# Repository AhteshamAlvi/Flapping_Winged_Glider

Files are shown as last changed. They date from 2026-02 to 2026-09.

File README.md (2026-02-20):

# Flapping Winged Glider (RoboRaptor)

Bio-Inspired Articulated Wing Glider for Wind Characterization and Flapping Flight Research

Ahtesham Alvi · Piyush Sethy · Saiarun Jayanthi <br>
FIRE Bio-Inspired Robotics — University of Maryland: College Park <br>
Advisor: Dr. Lena Johnson

---
## Table of Contents

- [Overview](#overview)
- [Research Goal](#research-goal)
- [Overview](#overview)
- [Final Firmware Version](#final-firmware-version)
- [Prototyping](#prototyping)
- [Mechanical Design](#mechanical-design)
- [Firmware and Control](#firmware-and-control)
- [Wind Sensing and Data Logging](#wind-sensing-and-data-logging)
- [Experimental Results](#experimental-results)
- [Repository Structure](#repository-structure)
- [Hardware Components](#hardware-components)
- [Key Engineering Insights](#key-engineering-insights)
- [Future Work](#future-work)
- [Acknowledgments](#acknowledgments)
- [License](#license)

---
## Overview

This project develops a bio-inspired, tethered flapping wing glider designed to investigate how atmospheric wind conditions interact with articulated wing kinematics in lightweight robotic flight systems. The platform combines a bird-inspired airframe, servo-actuated flapping wings, onboard sensing, and wind telemetry logging to experimentally characterize the behavior of mechanically flapping gliders under real wind conditions.

The system functions as an aeroelastic test platform rather than a powered drone. Instead of continuous propulsion, it leverages aerodynamic lift from wind while actively modulating wing motion through servo actuation. This enables controlled experiments on wind-assisted flight, flapping dynamics, and structural-aerodynamic coupling in lightweight robotic wings.

---

## Research Goal

The objective is to create a tethered gliding robot with articulating wings capable of measuring and characterizing how wind influences flapping and gliding behavior in bio-inspired aerial robots. The platform enables experimental study of atmospheric energy interaction with mechanical flapping systems and supports exploration of passive-active hybrid flight modes.

---

## Overview

This research project consists of four distinct parts (other than the final report):

Mechanical Structure <br>
A lightweight, bird-inspired winged airframe using carbon-fiber spars, flexible membrane wings, and 3D-printed servo mounts and joints designed to withstand cyclic flapping loads.

Actuation and Control <br>
Metal-gear high-torque servos drive articulated wing spars. Arduino-based firmware controls flapping motion, torque behavior, and receiver input for manual or programmed wing actuation.

Sensing and Telemetry <br>
Onboard sensors measure environmental and motion data (temperature, wind vector components, inertial motion). Data is logged via an OpenLog SD module for time-series analysis.

Experimental Validation <br>
Wind-dependent flight trials are recorded via telemetry logs and video to correlate aerodynamic performance with mechanical and control configurations.

---

## Final Firmware Version

The final integrated control firmware for the RoboRaptor platform is:

**CompleteCode_v6.ino**

This version consolidates:

* Servo flapping control
* High-torque actuation logic
* Receiver/remote input handling
* Sensor acquisition
* OpenLog SD telemetry output

Earlier firmware files (ControlCode_v*, PrecisionControl, HighTorqueMotorControl, etc.) represent intermediate development stages and are retained for reference and historical comparison, but **CompleteCode_v6.ino** should be used for deployment and experiments.

---

## Prototyping

Prototype 1 — Sparrow/Falcon Static Wings <br>
Wooden dowel frame with plastic film wings. Failed due to structural fragility and unstable joints.

Prototype 2 — Sparrow/Falcon with Actuation <br>
Introduced servo mounts and actuating spars. Wooden spars fractured under load during flight.

Prototype 3 — Eagle Glider <br>
Transitioned to carbon-fiber spars and improved wing geometry. Achieved stable gliding flight in winds above ~7 mph.

Prototype 4 — Eagle with Articulated Wings <br>
Integrated servo-driven flapping, electronics plate, and improved membrane material. Achieved controlled flapping and directional flight.

---

## Mechanical Design

The mechanical system focuses on load-bearing servo mounts and articulated wing spars capable of sustaining cyclic flapping stresses.

Key design features:

* Carbon-fiber structural spars for stiffness-to-weight efficiency
* Flexible membrane wings for aeroelastic deformation tolerance
* 3D-printed servo mounts optimized for fatigue resistance
* Modular covers and electronics enclosure
* Bird-inspired wing geometries (Sparrow, Falcon, Eagle models)

Multiple mount iterations reflect optimization for torque capacity, vibration damping, and oscillatory load survival.

---

## Firmware and Control

Arduino-based firmware evolved from simple servo tests to integrated flapping control with torque and input handling.

Functional modules include:

* Servo motion and flapping generation
* High-torque actuation control
* Precision timing and motion tuning
* Receiver input decoding
* Remote interface handling
* Sensor data acquisition
* OpenLog SD telemetry output

Later “CompleteCode” versions integrate these subsystems into a unified controller.

---

## Wind Sensing and Data Logging

Wind and motion data are recorded as time-series telemetry during flight tests. Logged values include environmental and inertial measurements sampled at ~30–35 Hz and written to SD via OpenLog.

Example telemetry fields:

* Timestamp
* Temperature
* Wind vector components
* Resultant wind magnitude
* Inertial motion (gyro/accel)

These datasets support analysis of aerodynamic response, flapping behavior, and environmental coupling.

---

## Experimental Results

The articulated Eagle prototype demonstrated:

* Stable tethered gliding in natural wind
*  Servo-driven flapping motion
*  Directional control capability
*  Successful onboard wind data logging

Performance confirmed that carbon-fiber spars and metal-gear servos resolved earlier structural and torque limitations.

---

## Repository Structure

```
Flapping_Winged_Glider/
  CAD/                      CAD and 3D-print files
  Field_testing_files/      Wind logs and videos
  Glider-Code/              Arduino control code
    basecode_files/           Building blocks of code files
  Final_Research_Report/    Report, poster, bibliography
```

---

## Hardware Components

Arduino Nano microcontroller <br>
MG92B metal-gear servo motors <br>
Carbon-fiber wing spars <br>
Flexible membrane wing material <br>
OpenLog SD data logger <br>
Environmental and inertial sensors <br>
3D-printed structural mounts and joints

---

## Key Engineering Insights

Flapping torque requirements exceed plastic servo capability <br>
Cyclic bending fatigue dominates mount design constraints <br>
Wing inertia and structural stiffness directly affect control tuning <br>
Wind magnitude strongly influences flapping stability <br>
Lightweight aeroelastic structures outperform rigid frames

---

## Future Work

Integrated multi-sensor suite (temperature, IMU, altimeter) <br>
Wireless telemetry transmission <br>
Improved membrane wing material (nylon fabric) <br>
Permanent sealed electronics enclosure <br>
Closed-loop wind-adaptive flapping control <br>
Expanded wing geometry optimization

---

## Applications

Atmospheric energy harvesting research <br>
Bio-inspired aerial robotics <br>
Lightweight flapping wing design <br>
Wind-assisted flight systems <br>
Environmental sensing platforms <br>

---

## Acknowledgments

FIRE Bio-Inspired Robotics Program <br>
University of Maryland: College Park <br>
Dr. Lena Johnson

---

## License

Educational and research use.

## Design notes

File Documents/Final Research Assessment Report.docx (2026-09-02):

Ahtesham Alvi, Piyush Sethy, Saiarun Jayanthi

Professor Lena Johnson

FIRE Bio-Inspired Robotics

July 19, 2024

Final Project Report

This project aimed to create a bird-inspired, tethered gliding robot (kite) with articulating flapping wings capable of measuring and characterizing the effects of atmospheric behavior and wind on mechanical flapping and gliding robots. It is primarily made for research purposes to measure wind since it is a kite glider with little practical application.

Our first prototype was a half-wing taped to a table. It was to figure out how to move the wing with a servo, or if it was even possible to do so with a single motor. The second prototype was taking that and splitting it into two distinct wing shapes, as well as stronger metal geared motors. One was model Sparrow, whose wing shape was based on a House Sparrow, and the other was model Falcon, whose wing shape was based on a Peregrine Falcon. The model Sparrow and Falcon both had too brittle spars because they were made of wooden dowels and black plastic film. So then we transitioned to model Eagle for our third prototype, based on a Golden Eagle. This one used carbon fiber rods and the same black plastic film. In the fourth and final prototype, we changed from a black film to a white one because the black film suffered from deformation in the sun. This model used lighter electronics with an Arduino Nano and an accelerometer but the same metal-geared servo motors.

We faced several technical and mechanical problems throughout the project. One primary challenge was the failure of plastic SG92R servos, which couldn’t adequately move the wing spar. We solved this problem by shifting to MG92B servos which had metal gears and a higher torque. We further faced issues with generating lift with prototypes one and two because of brittle wooden dowels, fragile plastic films and a bad wing shape. To solve this, we upgraded to carbon fiber dowels and used flexible garbage bags that allowed it to withstand strong winds. We also changed the wing shape to more closely resemble that of a bird (Eagle). Moreover, as we shifted our focus to programming the sensors to collect environmental data, we faced technical issues with transmitting or recording the data. This was because we lacked hardware and did not have the required SD card reader or transmitter.

In the future, we plan to use a more permanent nylon fabric and sow our electronics into the body. We would like to create a more permanent enclosure so that we can easily repair/modify the electronics, but not add too much weight, all while protecting them from the elements. Additionally, the goal of monitoring wind data flopped in the end. In the future, it would be better to have a more complete sensor system (temperature, gyroscope, accelerometer, and altimeter) that can also write to an easily accessible file, preferably remotely transmitting it to another device. This data could be used to create a more sophisticated control system. Lastly, we would like to iterate on the kite/wing shape itself: we didn’t have enough time or material to prototype lots of different shapes for the kite body.

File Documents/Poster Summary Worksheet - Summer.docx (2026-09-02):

Poster Summary Worksheet

Teams should use this worksheet to organize their research as preparation for creating their final poster presentation. There are no minimum writing requirements for each question but consider that you will take this information and put it in a poster presentation. Judge your responses accordingly.

Project Background

Write about the background research that informed your team’s robot design. Consider your use of the Application, Inspiration, Method (AIM) research method.

Application

Consider how your robot might be used in the field. For example, wildlife monitoring, water cleanup, or archaeology? Talk briefly about how you imagine it might be used.

Our bird-inspired, tethered gliding robot can be used in various practical applications as we take advantage of its ability to glide with the wind. For example, in wildlife monitoring, the robot's quiet, bird-like motion can aid in observing animals while minimizing disturbances. In environmental research, we can embed atmospheric sensors with the robot to measure wind speed, air pressure, humidity, and other properties. The robot's lightweight design and gliding capabilities also make it ideal for continuous atmospheric monitoring and data collection, as it can fly with the wind without external energy input.

Inspiration

Now explore the world of biology and consider what living thing (plant or animal) might inform a robot design that would fit your application. Consider the field application environment and what animals have adapted to it. Also, you can think about natural capabilities in general that might improve the robot design.

Describe what specific traits, forms, functions or behaviors make this a good robot inspiration (For example, can it go deep underwater? Traverse different terrains? Get into small holes?).

Traits across different avian species have inspired our robot design. Our design has large wings and a lightweight design influenced by the biology of dynamic soaring, as birds can detect wind gradients and adjust their flight path for maximum efficiency. By prototyping our robot based on these traits, we utilized these features to fly more efficiently without relying on extended battery usage. Moreover, we also mimicked the adaptive wing features of eagles and hawks to optimize our different flight modes, such as gliding without constantly flapping.

Evaluate the inspiration’s taxonomy. Where does it sit in the taxonomy charts? What specific taxonomic traits are shared across the family or the order that are of use.

The taxonomy of the three birds that inspired our robot design are:

- Hawk → Order: Accipitriformes, Family: Accipitridae
- Sparrow → Order: Passeriformes, Family: Emberizidae
- Eagle → Order: Accipitriformes, Family: Accipitridae
  - We designed our wings to be adaptive so they can flap and glide. Hawks and eagles combine flapping with gliding to optimize energy use during flight. Moreover, eagles have strong, versatile wings that can adjust shape for various flight conditions, so we incorporated them into our design.
- Albatross → Order: Procellariiformes, Family: Diomedeidae
  - Albatrosses have lightweight bodies and large wingspans, which allow them to use wind energy to stay aloft with minimal flapping and thus conserve a lot of energy.

Mechanism

Breakdown the mechanism by which the creature does its thing. Does it crawl, fly, walk, slither? What muscles, body structures, organs or sensors enable this function?

- https://flexbooks.ck12.org/cbook/ck-12-advanced-biology/section/16.32/primary/lesson/bird-structure-and-function-advanced-bio-adv/
- https://www.frontiersin.org/journals/physiology/articles/10.3389/fphys.2020.01038/full

Aside from their well-developed wings, hawks and eagles have numerous structural adaptations that allow them to perform exceptionally well in various conditions. Their skeletons are lightweight yet maintain the strength required to withstand powerful winds. Their bones are fused together in their skeleton, creating rigidity at the joints. This allows them to withstand any stress or concussion generated during maneuvering mid-air. Their keeled sternum provides strong anchorage for powerful flight muscles like the pectoralis major, and together, they can generate the strong wing strokes required for flight. Furthermore, the respiratory system of birds, distinguished by distinct air sacs and parabronchi, helps them to meet the high metabolic demands of flight.

What are the biophysics or physics principles that underly this mechanism? For example, does the animal use Lift to overcome Drag and fly? Does the creature expand and contract with Tension? Does it swim because it is very buoyant?

The robot's design is derived from that of a delta kite. This enables it to catch the wind without relying exclusively on the flapping mechanism to generate lift. Two important considerations are the robotic system's weight and the drag it experiences as it glides. The robot is designed to avoid becoming unbalanced and veering off course.

Project Goal and Design

Describe the goal and design of your robot. Discuss your design process. In other words, how your design was developed? How did you go from original concept design to final idea?

The project aims to create a bird-inspired, tethered gliding robot (kite) with articulating flapping wings capable of measuring and characterizing the effects of atmospheric behavior on mechanical gliding. We followed an iterative design process, continuously improving different parts of the design. At first, we studied several research papers on flapping mechanisms and traits of various bird species to understand the physics of bird flight. Based on the insights we got from research and flying a delta kite, we created basic sketches of different delta kites with rough dimensions for our spars. Moreover, we centered our design choices on two wing shapes to experimentally deduce the most efficient wing shape. While prototyping, we considered several different materials, such as wooden dowels, carbon fibers, and clear and black plastic film. Finally, we created four prototypes and tested them over time. Based on several flight tests, we decided to design our kite with carbon fiber and plastic film.

Briefly consider how the bio mechanisms you found might inform a design? What do you think is the technological analog to the mechanism? Would the design be large or small? Use motors, propellors or wings?

The main biomechanics that informed our design was the flapping mechanism. While birds use their powerful sternum and pectoral muscles to produce powerful wing strokes, we had to iteratively design different methods to replicate this motion. At first, we couldn’t generate the flapping motion in the spar as the SG92R servo was too weak to move the wooden spar. Also, it heated up too quickly. We upgraded to high torque and metal MG92B servos and achieved a consistent flapping mechanism. We were able to move the wing spar for several minutes continuously before the servo heated up.

Current Progress

Describe the current progress your team has made on your robot project.

Describe your concept sketches. How did they help your team create a mind map of the possible ideas? How did your team eventually narrow down the ideas to your final concept? What parameters did you use to “test” the different ideas?

The two initial designs are referred to as Sparrow and Falcon. Sparrow uses a wider wing design with several supporting spars. The bigger surface area was theorized to gather atmospheric wind more efficiently, generating a greater amount of lift.

Falcon uses a curved, sharper wing with no supporting spars. This design was built to emulate the streamlined nature of several avian species with high-speed wing shapes.

While brainstorming sketches, we considered several parameters, including aerodynamic efficiency, structural integrity, and weight. Our initial designs were lightweight, but the joint structures were weak, so they could not support their own weight. We designed and printed connectors to improve the overall integrity of the kite.

Describe the systems of your final idea. What type of systems did your team design? What was the overall shape of the robot? What kind of actuation are you planning? What materials will it be made of? How are you proposing to design the electric circuit? Include pencil sketches and CAD models if you have them.

The final iteration is referred to as Eagle. The weight of the electronics became a concern, so an Arduino Nano with a smaller battery and a smaller breadboard was used. Eagle uses a thinner carbon fiber rod frame for increased flexibility and durability. Additionally, we decided to change the color of the plastic material from black to white because the black material heated too quickly in the sun and deformed during flight.

Describe the preliminary prototypes of your robot. Have you done any testing? What was the outcome? How did it affect the design?

Our preliminary prototypes were made from wooden dowels and plastic film. We carved out two sketches for the wing shape, and based on those, we prototyped and tested both of these designs in the field. Unfortunately, both of these prototypes only took flight for a few seconds. While several variables are crucial for winged robots to take and stay in flight, we deduced that factors like the stiff dowels and fragile bags were the primary reasons behind the failed kite test. Moreover, we considered changing the design of our wings as it was possible that they weren’t catching enough air for lift. After all these design considerations and testing, our final design is made from carbon fibers and stronger plastic film that withstands the constraints of flight.

Team Kite

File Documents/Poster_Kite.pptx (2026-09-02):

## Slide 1

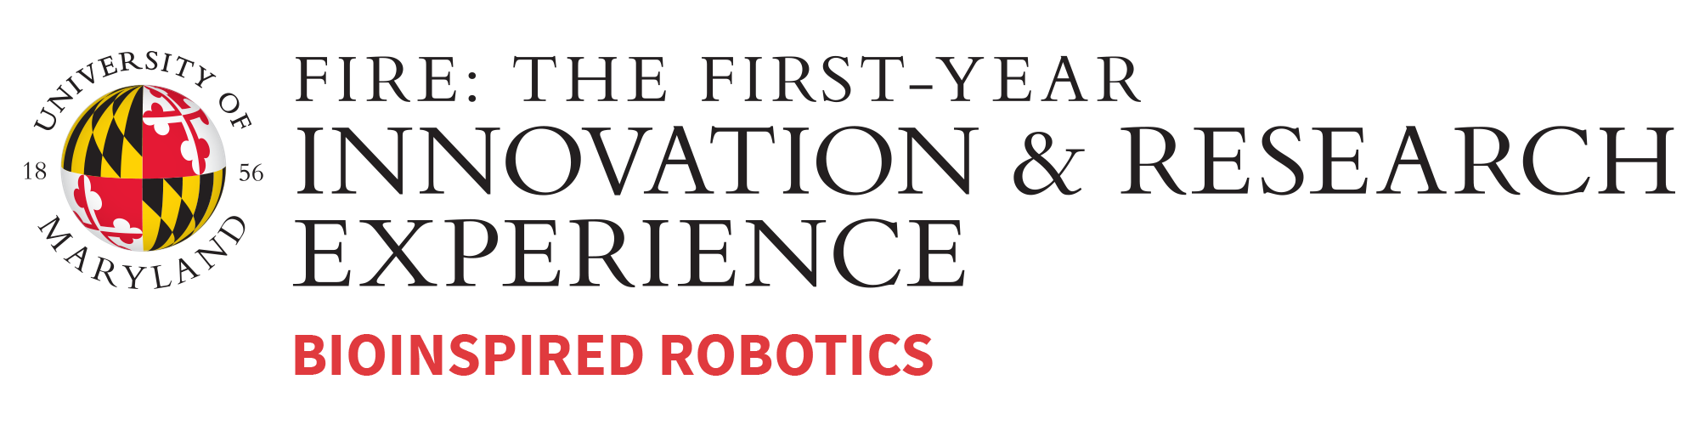
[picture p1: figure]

Goal

This project aims to create a bird-inspired, tethered gliding robot (kite) with articulating flapping wings capable of measuring and characterizing the effects of atmospheric behavior and wind on mechanical flapping and gliding robots.

RoboRaptor: Articulated Wing Glider
Ahtesham Alvi, Piyush Sethy, Saiarun Jayanthi, and Dr. Lena Johnson

Prototype 1: Sparrow & Falcon

- Large wings made with plastic film and a lightweight frame made up of wooden dowels
- Failure: Unable to fly due to unstable joints and fragile plastic body

Prototype 2: Sparrow & Falcon with Actuating Wings

- Improved design with 3D printed servo mounts, end connectors, servo wing spars, and a middle hinge connector
- Used flexible black film, which was more resistant to wind
- Incorporated electronics and servos into the kite
- Failure: Wooden dowels were too stiff and broke during flight test

Prototype 3: Eagle

- Transitioned the frame from wooden dowels to carbon fiber and aluminum
- Adjusted the wing shape based on dimensions of an eagle
- Success: Was able to take flight with winds above 7 mph

Prototype 4: Eagle with Actuating Wings

- Added servos and actuating wings with 3D printed wing arms and mounts
- Used a white film as it is lighter and better suited for hotter climates
- Used a 3D printed plate to incorporate all electronics, including wind sensor
- Success: Was able to fly with the ability to flap and turn

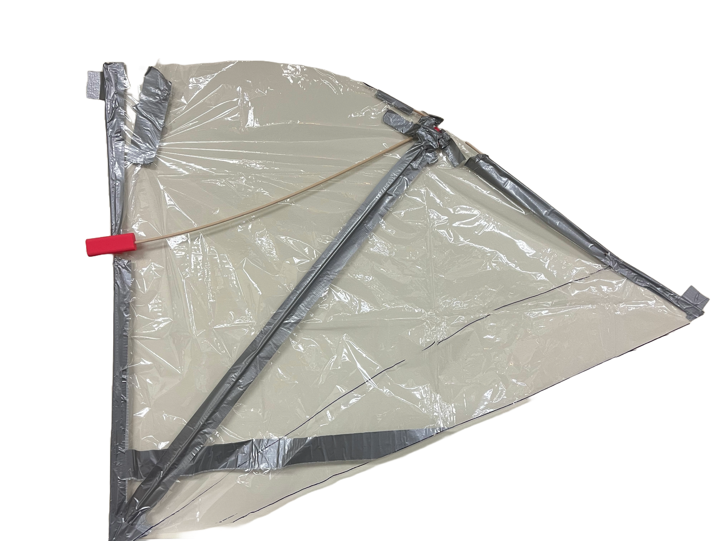
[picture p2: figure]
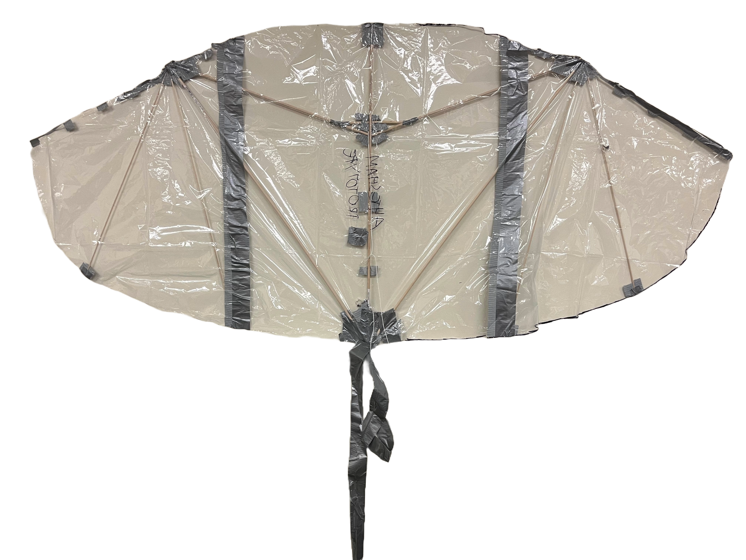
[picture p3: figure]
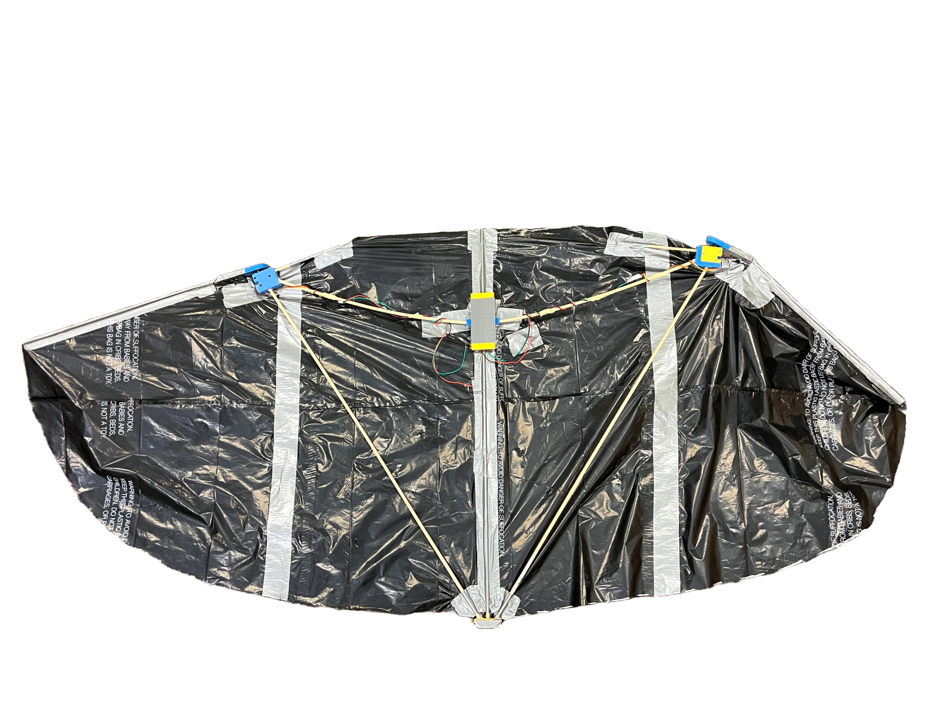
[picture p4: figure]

Background

Unlike traditional drones which require a constant external power source for propulsion, gliding robots leverage aerodynamic efficiency to sustain flight by using the gliding and soaring behavior of birds. [1] This enables them to fly without requiring continuous power input, making them especially valuable for environmental monitoring and data collection. [2]

Governing Principles

Aspect Ratio: The ratio of the length of the wings to their width. It is calculated by dividing the square of the wingspan by the area of the wing. [3] Our kite has a high aspect ratio, which enables it to glide without relying exclusively on flapping
to generate lift.

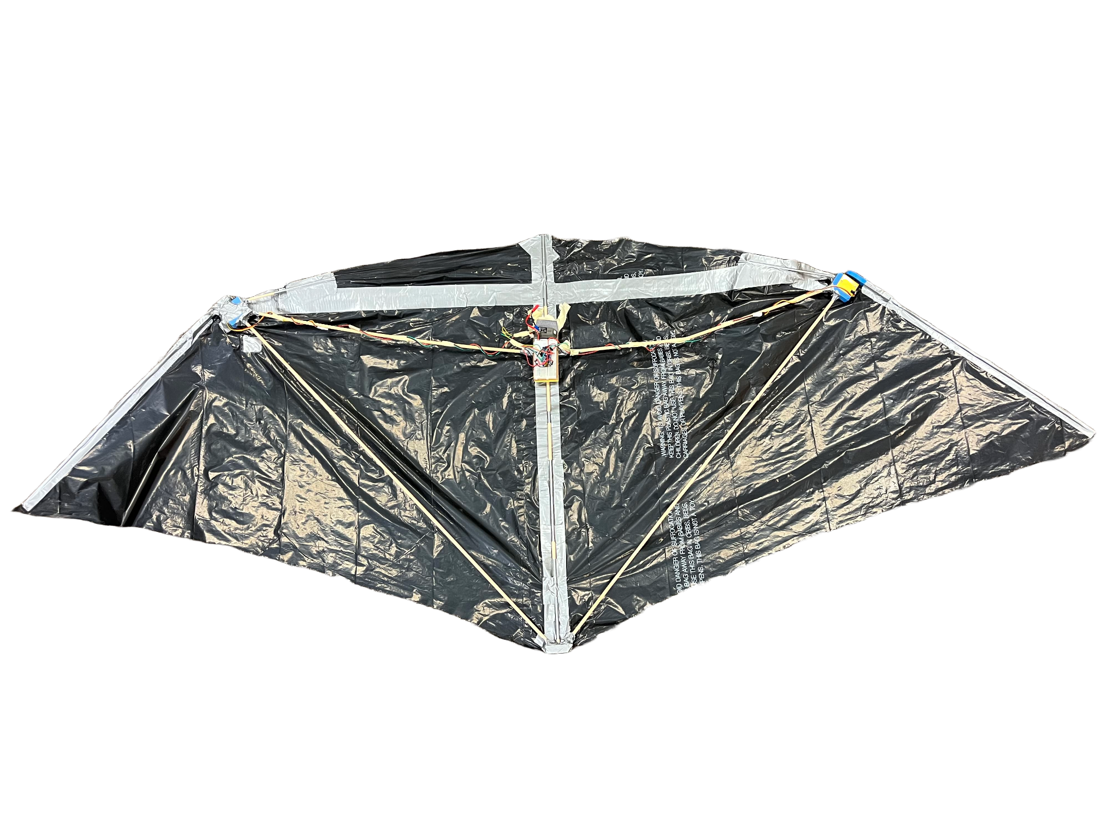
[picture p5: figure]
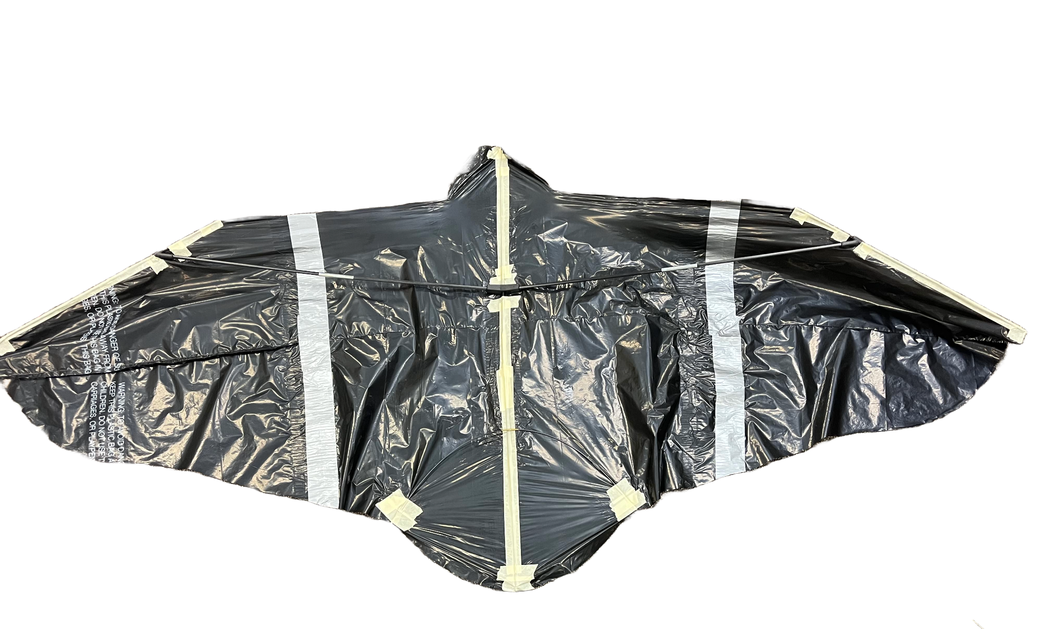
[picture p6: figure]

Wind Data:

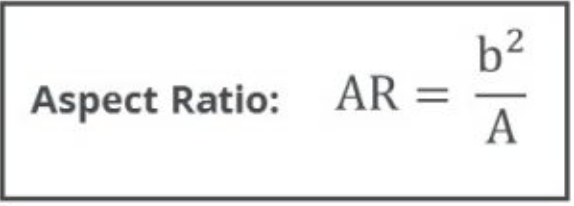
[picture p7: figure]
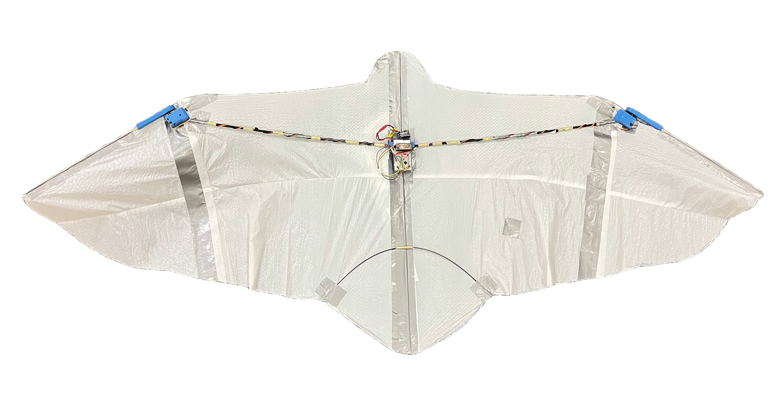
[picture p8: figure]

References
[1] A. Mohamed, G. K. Taylor, S. Watkins, and S. P. Windsor, “Opportunistic soaring by birds suggests new opportunities for atmospheric energy harvesting by Flying Robots,” Journal of The Royal Society Interface, vol. 19, no. 196, Nov. 2022. doi:10.1098/rsif.2022.0671
[2] A. Khaheshi, H. T. Tramsen, S. N. Gorb, and H. Rajabi, “Against the wind: A load-bearing, yet durable, kite inspired by insect wings,” Materials &amp; Design, vol. 198, p. 109354, Jan. 2021. doi:10.1016/j.matdes.2020.109354
[3] “Aircraft Wing area and aspect ratio,” AeroToolbox, https://aerotoolbox.com/intro-wing-design/ (accessed Jul. 17, 2024).
[4] D. B. Savile, “Adaptive evolution in the avian wing,” Evolution, vol. 11, no. 2, p. 212, Jun. 1957. doi:10.2307/2406051
[5] “House Sparrow Overview, all about birds, Cornell Lab of Ornithology,” Overview, All About Birds, Cornell Lab of Ornithology, https://www.allaboutbirds.org/guide/House_Sparrow/overview (accessed Jul. 17, 2024).
[6] “Peregrine Falcon Overview, all about birds, Cornell Lab of Ornithology,” Overview, All About Birds, Cornell Lab of Ornithology, https://www.allaboutbirds.org/guide/Peregrine_Falcon/ (accessed Jul. 17, 2024).
[7] “Golden Eagle Overview, all about birds, Cornell Lab of Ornithology,” Overview, All About Birds, Cornell Lab of Ornithology, https://www.allaboutbirds.org/guide/Golden_Eagle/ (accessed Jul. 17, 2024).

House Sparrow [4,5]

Scientific Name: Passer domesticus
Wing Shape: Elliptical Wing
Wingspan: 25.4 cm
Sparrow Aspect Ratio: 5.5
Model’s Aspect Ratio: 2.92

- Sparrows have wide, rounded wings, which allow for greater control
- The larger wing width allows for the model to generate greater lift
- The wider wings also tend to increase the drag force on the kite

Peregrine Falcon [4,6]

Scientific Name: Falco peregrinus
Wing Shape: High Speed Wing
Wingspan: 81.8 cm
Falcon Aspect Ratio: 7.9
Model’s Aspect Ratio: 4.29

- Falcons have a keeled sternum and powerful wing muscles
- They have adaptive wings that can adjust shape for various flight conditions
- The model’s curved wing shape aids in reducing drag

Golden Eagle [4,7]

Scientific Name: Aquila chrysaetos
Wing Shape: Slotted High Lift Wing
Wingspan: 194 cm
Eagle Aspect Ratio: 7.4
Model’s Aspect Ratio: 6.24

- Their wings are more rounded than a falcon’s but are narrower than a sparrow’s
- Allows for reduced drag, increased lift, and cutting through the air
- The model’s wing contains an inward curve despite its narrower wings

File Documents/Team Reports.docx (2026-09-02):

5/31

Section 2: Team Report (To be done as a team. All team members can copy and paste their collective report into this section)

Write about the progress your team has made on the project. How does this fit into the overall goal of the summer?

- We have created conceptual sketches and diagrams of the kite design. We have also worked to identify potential materials and components for the wings, body, and control systems.

- This fits as the first stage into the overall summer goal to create a functioning robot glider. It is part of the preliminary design which is a crucial first step in creating the first prototype of the robot glider.

What do you plan to accomplish on the project next week?

- Our plan for next week is to create a simple kite prototype from wooden sticks and a garbage bag and test it to ensure it can fly. We already have the dimensions of the kite figured out and want to build a quick and disposable prototype to test the flight dynamics first. If this prototype kite successfully flies, we will then 3D print plastic parts and use those dimensions for our robot glider. This iterative approach will help us refine our design and ensure reliability.

6/7

Write about the progress your team has made on the project. How does this fit into the

overall goal of the summer?

- We figured out the basic dimensions of our kite, and two viable shapes for the kites and wings.
- We figured out how to read signals for the controllers and wrote code to find the values that the controller was sending to the receiver and interpret them into useful directions.
- Made the configuration for the motors so that it works with a separate battery source.
- Learned the functions of the different receiver pins and their responses on the controller.
- Designed the connector from the servo to the spur.

What do you plan to accomplish on the project next week?

- Next week we plan to build our first two prototypes and test the wing mechanisms on Hawk 1 Model Sparrow and Model Falcon.
- We also will write the basic code for the wing flapping and the wing movements in order to make the prototypes.
- Fly the new prototypes.
- 14/7

6/14

Section 2: Team Report (To be done as a team. All team members can copy and

paste their collective report into this section)

Write about the progress your team has made on the project. How does this fit into the

overall goal of the summer?

We have developed code for remote and Bluetooth control, and the jittering problem has been reduced. Additionally, we have designs for wing testing and kite joints. What remains is determining the ideal wing design and flapping motion. Our code also adjusts wing positioning for turning and provides constant flapping.

What do you plan to accomplish on the project next week?

Printing and testing flapping to find an ideal wing shape and design. Prototype wing shape on a kite. Write code that adjusts angle while flapping simultaneously.

6/21

Section 2: Team Report (To be done as a team. All team members can copy and

paste their collective report into this section)

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

overall goal of the summer?

We developed what should be a polishedish v1 for our arduino program. It has different modes that you switch between by turning on and off the throttle. One mode is constant flapping one mode set position. We have 3 more directional inputs we can fill with other mechanisms like a rutter/nose control. We printing our kite mounts and built a wing prototype, but the servo had an extremely tough time trying to move that kind of weight. We burned up maybe 2 other motors with similar shenanigans.

What do you plan to accomplish on the project next week?

We need to get a wing design and motor configuration that moves. We spent a lot of time thinking about how to make a body that can withstand field conditions but never expected the electronics to crap out.

6/28

Section 2: Team Report (To be done as a team. All team members can copy and

paste their collective report into this section)

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

overall goal of the summer?

- We created two kite prototypes with different wing dimensions to determine which design would perform better. After testing them, we found that our prototypes were unsuccessful.
- We realized that the wingspan was not large enough to achieve proper flight, and the plastic film used for the wings was not ideal, lacking the necessary aerodynamic properties.
- We got new servo motors that can handle the weight of the wing from the end dowel. It can run for a couple minutes straight while only getting slightly hot. We learned that instead of the 0 - 180 standard or 1000-2000 standard, the servo takes 700-2300 except sike it actually takes 700-2294 because why not.

What do you plan to accomplish on the project next week?

- We plan to 3D print several attachment parts like the 4-way spar connectors. We will then use these attachments to make an improved kite prototype.
- We also plan to use a new fabric or plastic film that is more stable than our current kite fabric.
- Moreover, we are planning to use a two-servo design for each wing, as our research has shown that a single servo is insufficient to fully control the wing when flying with the wind.
- We need to test the practicality of mounting our electronics to the kite, especially since the new motors are heavier and we might need several.
- We plan to stablize the ends of Piyush’s design with both dowels and motors and run a field test.

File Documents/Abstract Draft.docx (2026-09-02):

Kite Hawks Abstract

Current Unmanned Aerial Vehicle (UAV) flight times are limited by the life and technology of their onboard batteries. Natural flyers, in contrast, are adept at using atmospheric phenomena (wind gusts, thermals, etc) to increase their flight time without flapping. By considering the natural advantages of these flyers, methods might be developed to lend that advantage to UAV technology. This project aims to develop a robotic kite system with articulating wings and onboard sensors that can measure wind changes while exhibiting a gliding behavior. The hope is that the information gleaned from this platform might inform future gliding UAV design choices.

The design of this UAV is derived from existing delta kites, modified for a flapping wing purpose. Currently, this project is experimenting with two designs. One is an elliptical wing design based on the wings of a sparrow (Model Sparrow), and the other is a high-speed wing design based on the wings of a falcon (Model Falcon). Both work through the same servo mechanisms but use different angles for wings and supports, as well as other nose and tail shapes. The base is modeled from a kite, so it generates lift passively, while the wings are primarily for control in the air. The project is being tested for its flying capabilities and is currently under development.

Rough

Current Unmanned Aerial Vehicle (UAV) flight times are limited by the life and technology of their onboard batteries. Natural flyers, in contrast, are adept at using atmospheric phenomena (wind gusts, thermals, etc) to increase their flight time without flapping. By considering the natural advantages of these flyers, methods might be developed that can lend that advantage to UAV technology. The purpose of this project is to develop a robot kite with articulating wings and onboard sensors that can measure wind changes while exhibiting a gliding behavior. The hope is that the information gleaned from this platform might inform future gliding UAV design choices.

Here talk about your chosen design (what are you using? i.e servos, boxes)

The design of this UAV is derived from existing delta kites, modified for a flapping wing purpose. Currently, two designs are being experimented with. One is an elliptical wing design based on the wings of a sparrow (Model Sparrow), and the other is a high-speed wing design based on the wings of a falcon (Model Falcon). Both work through the same servo mechanisms but use different angles for wings and supports, as well as different nose and tail shapes. The base is modeled from a kite, so it generates lift passively, while the wings are primarily for control in the air.

What is a small finding or result that you currently have?

The project is currently being tested for its flying capabilities and is under development.

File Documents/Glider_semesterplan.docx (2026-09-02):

1. Concept Development (complete by Week 2)

Initial Design Sketches:

- Create conceptual sketches and diagrams of the kite design.
- Identify potential materials and components for the wings, body, and control systems.
2. Preliminary Design (complete by Week 3)

System Requirements:

- Define the technical specifications and performance criteria.
- Determine the weight, size, power requirements, and control mechanisms.

Simulation and Modelling:

- Use computational tools to simulate flight dynamics and aerodynamics.
- Develop a CAD model of the kite.

Initial Prototyping:

- Build a small-scale or simplified prototype to test basic concepts (make our own mini kites or order cheap ones from Alibaba)
- Conduct initial tests to assess feasibility and identify issues.
3. Detailed Design (complete by week 4)

Refine CAD Models:

- Create detailed CAD models incorporating feedback from initial tests.
- Include precise dimensions, material properties, and component placements.

Develop Control Algorithms:

- Design algorithms for wing flapping, angle of attack adjustment, and soaring control.

Full-Scale Prototype:

- Construct a full-scale prototype using the selected materials and components
- Ensure all systems (mechanical, electrical, control) are integrated and functional (sow the electrical components on the poles of the kites)
4. Testing and Iteration (completed before presentation)

Initial Flight Tests:

- Conduct controlled environment tests to evaluate basic flight performance.
- Perform tethered outdoor tests to assess real-world flight dynamics and stability.

Data Collection:

- Use sensors to collect data on wing flapping frequency, amplitude, atmospheric conditions, and flight behaviour.
- Analyse data to understand the kite's performance and identify areas for improvement.

Iterative Design Improvements:

- Make design adjustments based on test results (e.g., wing shape, material selection, control algorithms).
- Build and test revised prototypes to validate improvements.

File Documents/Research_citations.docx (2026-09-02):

05/29/2024

- https://www.sciencedirect.com/science/article/pii/S026412752030890X (Against the wind: A load-bearing, yet durable, kite inspired by insect wings)

05/30/2024

- https://royalsocietypublishing.org/doi/10.1098/rsif.2022.0671
- https://journals.sagepub.com/doi/full/10.1177/0278364914541301

06/03/2024

- https://www.sciencedirect.com/science/article/pii/S1367578821000171 (Decoding and realizing flapping flight with port-Hamiltonian system theory)

06/07/2024

- ChatGPT. (GPT-4). OpenAI. Accessed: Sep. 26, 2023. [Online]. Available: https://chat.openai.com/chat
- Code for getting output/receiver values from the Spektrum DXs controller.

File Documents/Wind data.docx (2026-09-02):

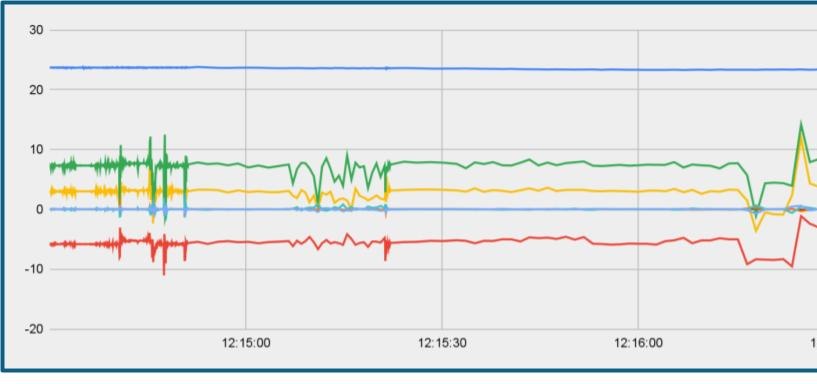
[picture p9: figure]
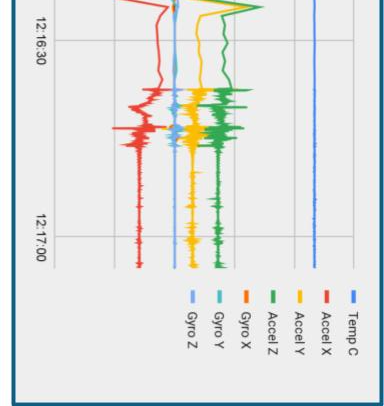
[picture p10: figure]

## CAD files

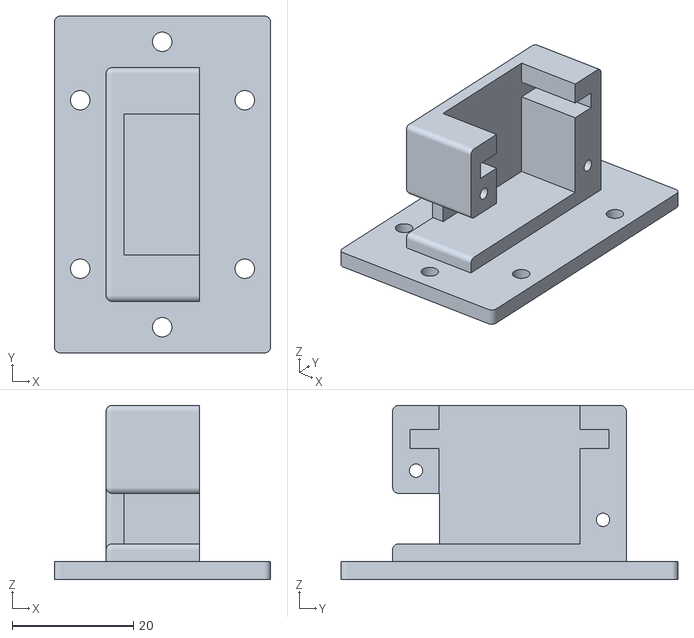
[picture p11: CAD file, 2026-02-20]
CAD/main.stl
35.6 x 55.5 x 28.7

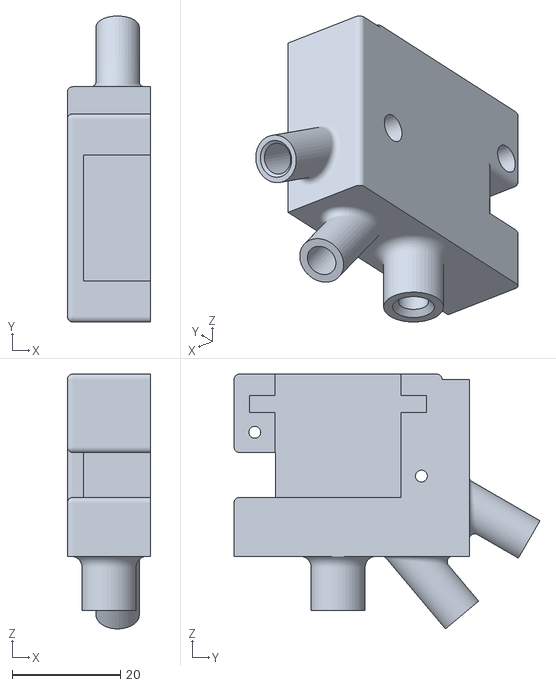
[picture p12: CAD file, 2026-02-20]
CAD/Ahtesham_servo mount.stl
15.4 x 56.6 x 47.1

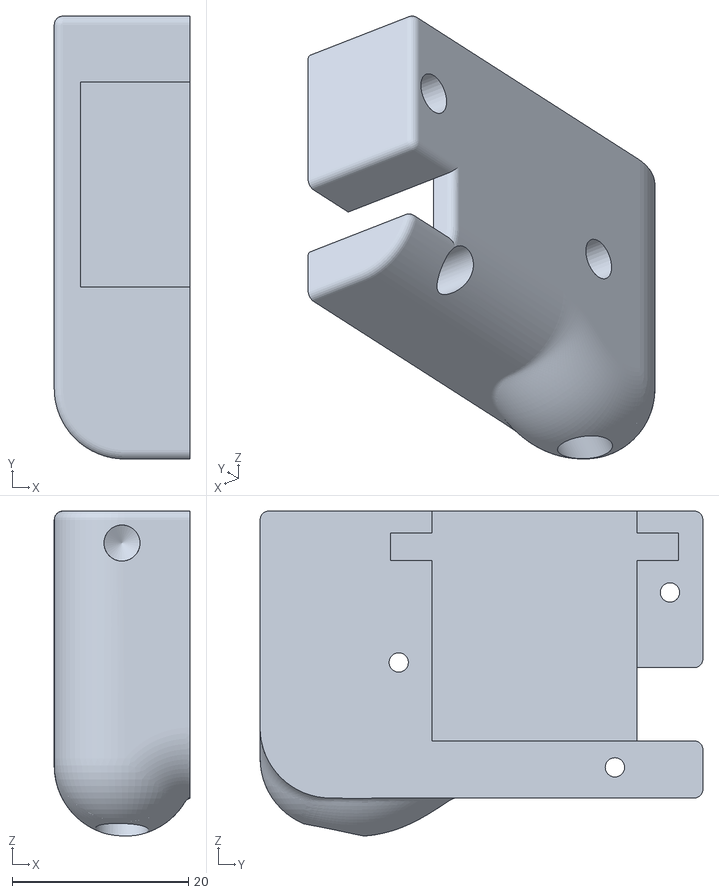
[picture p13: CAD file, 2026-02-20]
CAD/Prototype 5 Servo Mount Light v5.stl
15.4 x 50.3 x 36.9

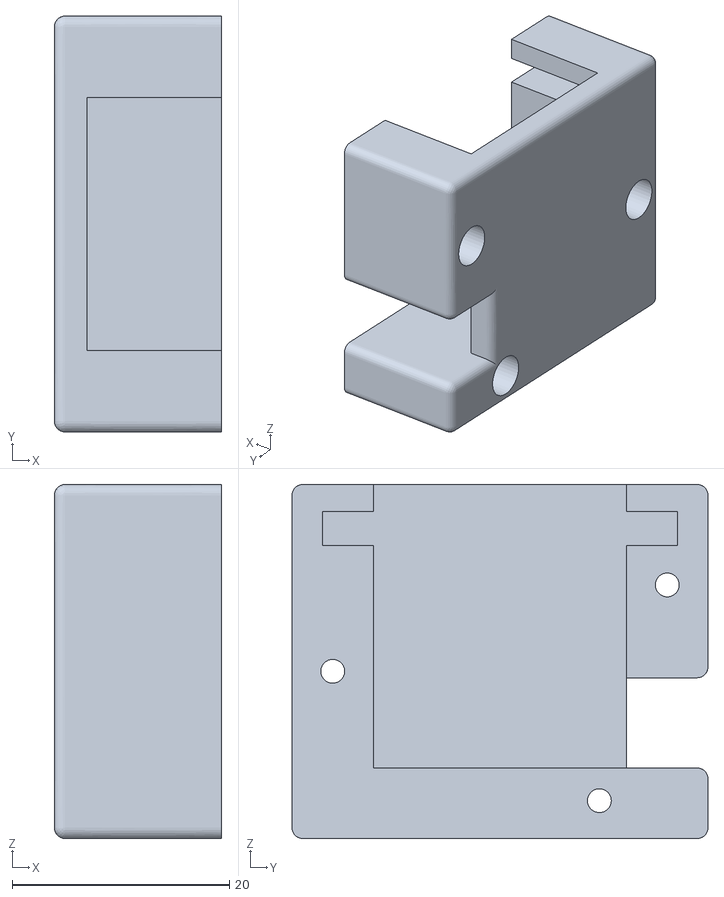
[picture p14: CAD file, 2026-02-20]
CAD/Basic Servo Mount Model.stl
15.4 x 38.3 x 32.6

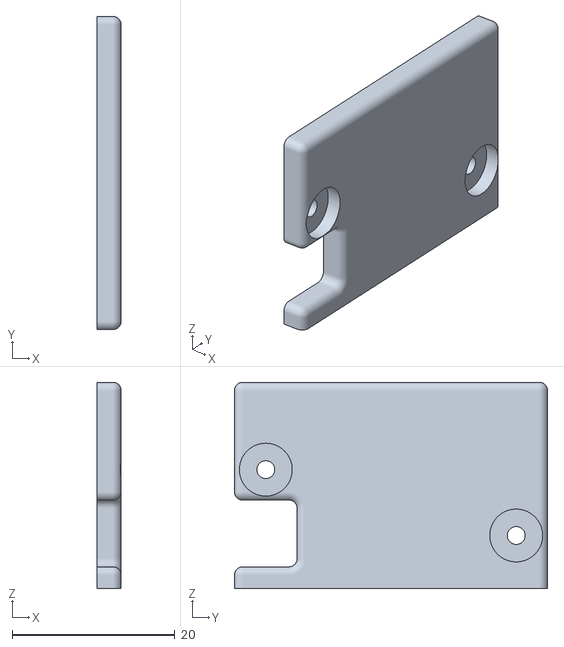
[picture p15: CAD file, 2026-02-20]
CAD/cover.stl
3.00 x 38.5 x 25.4

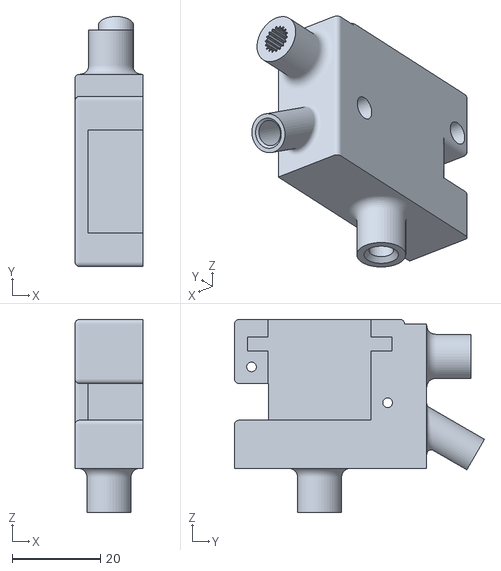
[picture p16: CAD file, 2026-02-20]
CAD/Piyush_design servo mount.stl
15.4 x 56.6 x 43.7

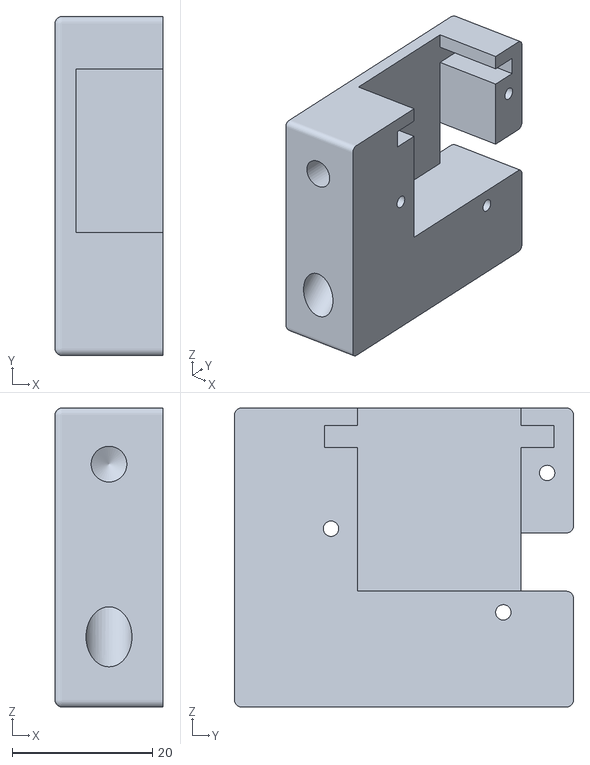
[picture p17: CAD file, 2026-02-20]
CAD/New Servo Mount Model v1 v2.stl
15.4 x 48.3 x 42.6

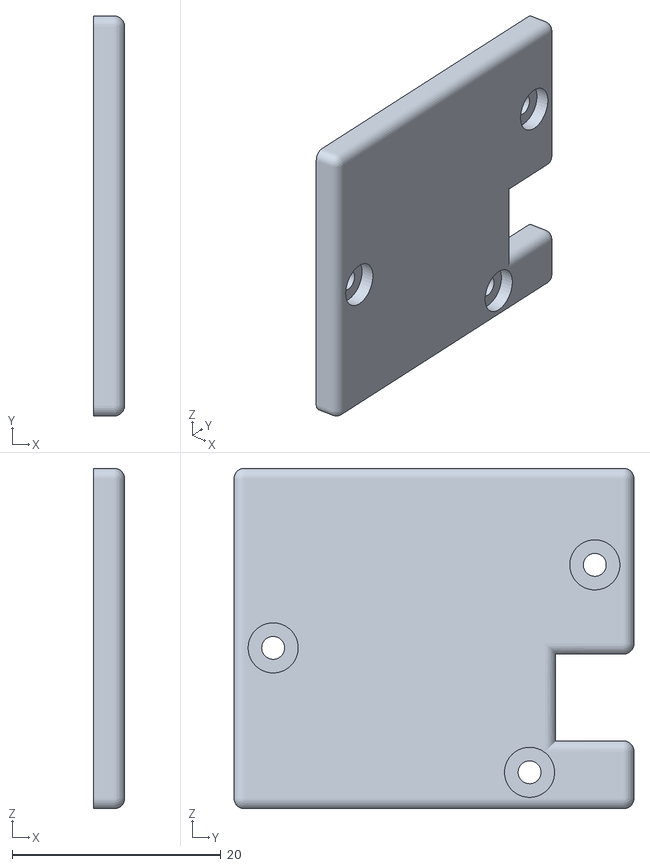
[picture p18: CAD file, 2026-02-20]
CAD/ServoCovers.stl
3.00 x 38.3 x 32.6

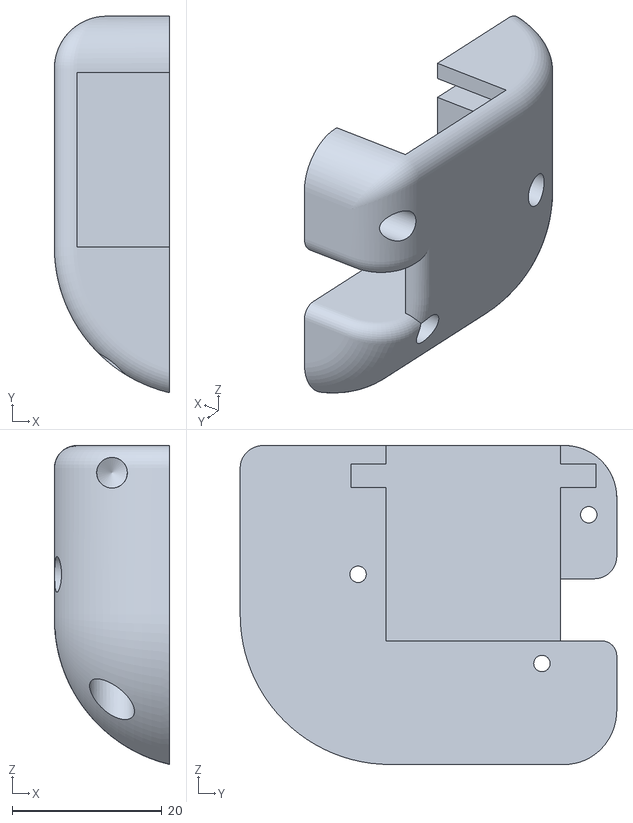
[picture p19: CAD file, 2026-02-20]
CAD/Prototype 5 Servo Mount Square v2.stl
15.4 x 50.3 x 42.6

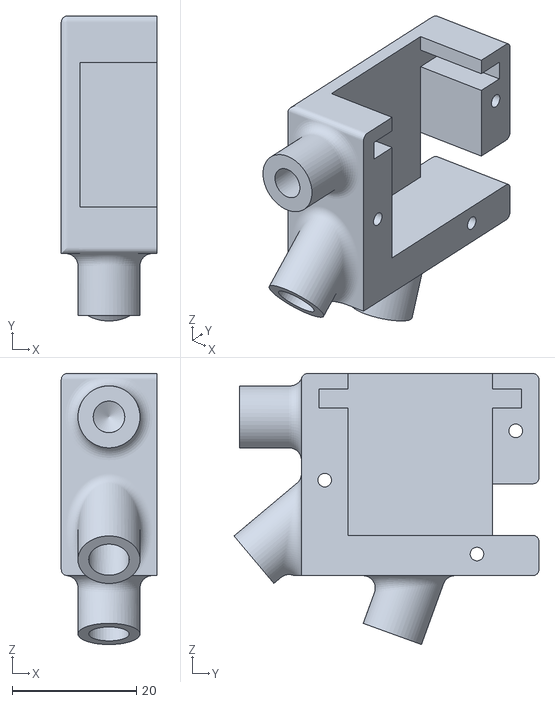
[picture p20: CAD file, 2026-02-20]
CAD/SparrowServoMount_v1.stl
15.4 x 49.2 x 43.7

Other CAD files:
CAD/Prototype 5 Servo Mount Light v4.stl
CAD/Cover_v1 v2.f3d
CAD/New Servo Mount Model v1 v1.f3d
CAD/Prototype 5 Servo Mount Light v5.f3d

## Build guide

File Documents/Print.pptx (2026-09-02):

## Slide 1

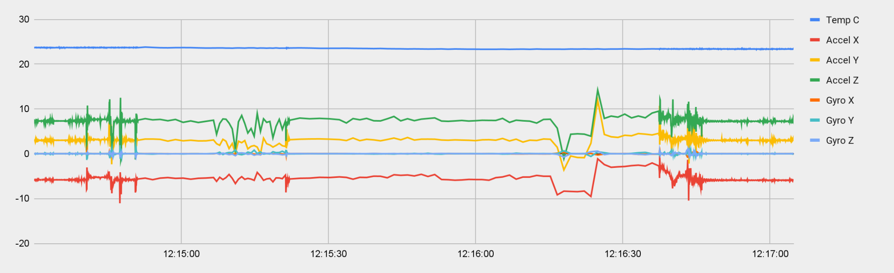
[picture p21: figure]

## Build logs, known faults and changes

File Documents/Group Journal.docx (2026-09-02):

5/29/2024

Got together with the group. We started talking about the basics of kite design but did nothing. Got meeting times down.

5/30/2024

Made a plan for the coming weeks. Planned the first prototype. The idea is to glue together some dowels and trash bag film to make a delta kite, then test it.

6/05/2024

- We connected the servo to gemma mo and used arduino IDE to create basic servo movement

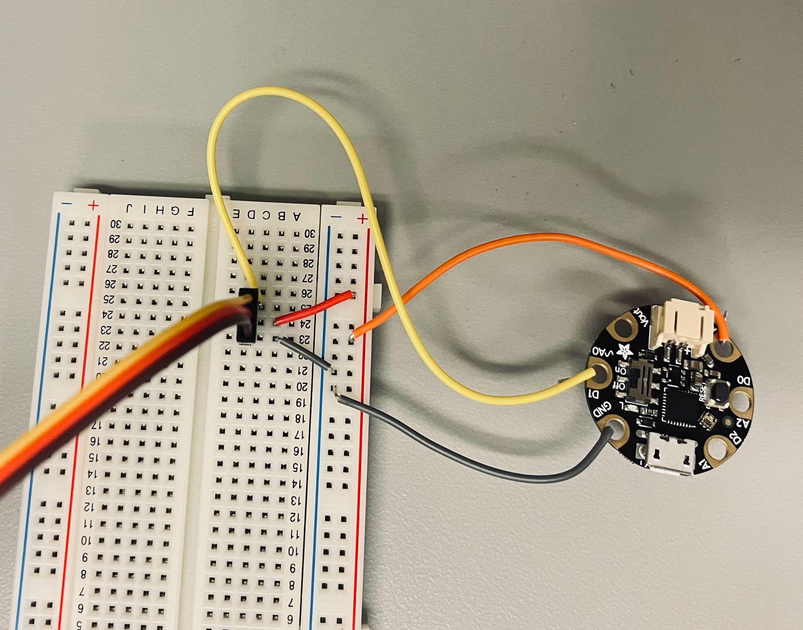
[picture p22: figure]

- To set up arduino IDE for gemma mo:
1. Go to IDE settings and type in https://adafruit.github.io/arduino-board-index/package_adafruit_index.json in the Additional boards manager URLs. Click OK.
2. Go to Tools>Board>Board Managers> and install Adafruit SAMD Boards
3. Then go back to Tools> Board>Adafruit SAMD boards> choose Adafruit Gemma Mo
4. Then go to Programmer> choose Atmel-ICE
5. Then go to Port and choose the appropriate port where the Gemma is connected
6. Start coding> press upload
- Parts to design:
- We need to start designing a connecter that holds connects the servo to the wings’ spar so that we can move the wings up and down
- We also need to design a holder for the servo that will sit on the middle spar

06/06/2024

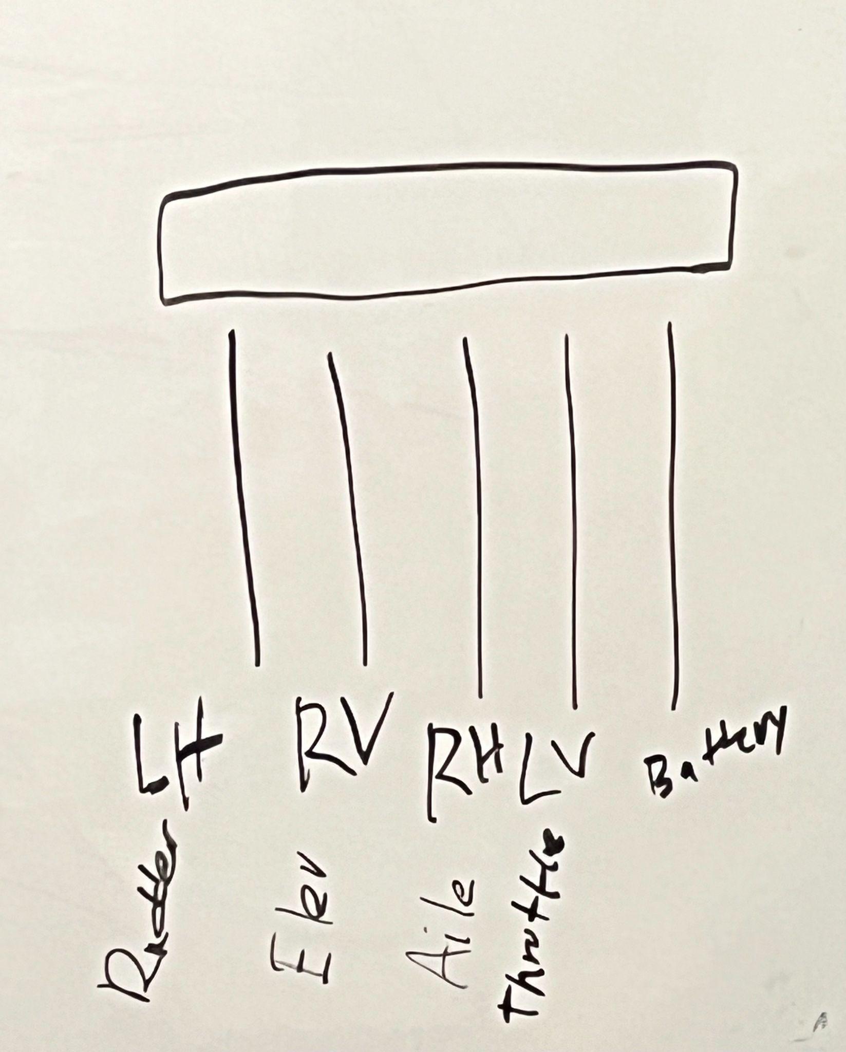
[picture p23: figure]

06/07/2024

Channel Values for Spektrum Controller

| -a (min) | 0 | +a (max)
Thot (2) | 1098 | 1468 | 1880
Aile (3) | 1777 | 1470 | 1191`
Elev (4) | 1317 | 1605 | 1895
Budder (5) | 1780 | 1490 | 1200

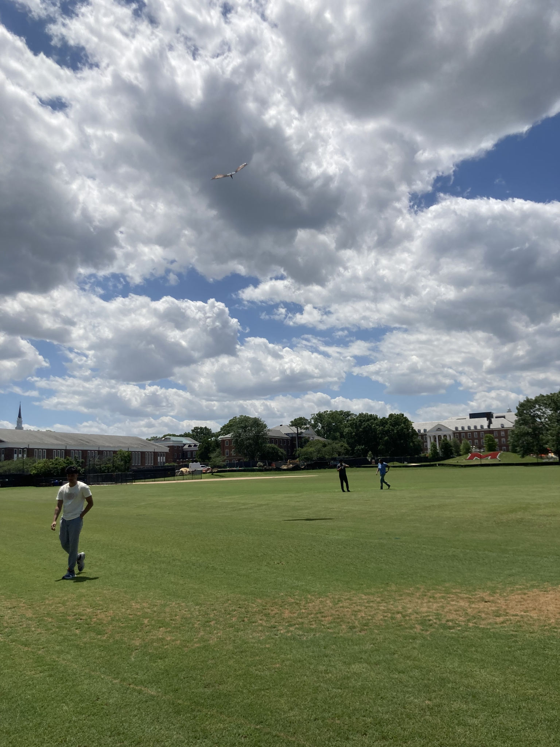
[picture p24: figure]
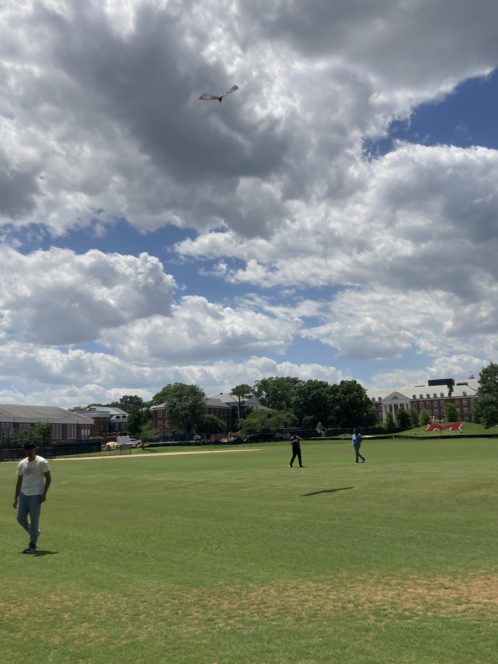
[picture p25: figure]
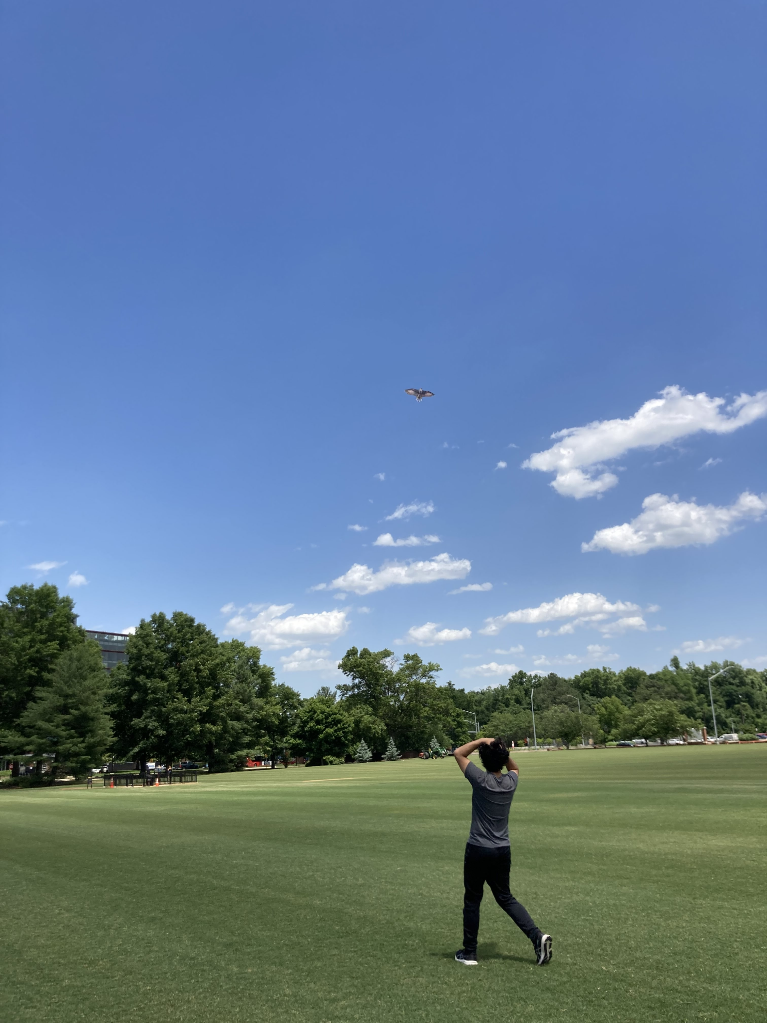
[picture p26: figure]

6/10/24

Sai Retest

Min/Max

| -a (min) | 0 | +a (max)
Battery (2) | — | — | —
Thot (3) | 1084 | 1468 | 1893
Aile (4) | 1844 | 1470 | 1039
Elev (5) | 1207 | 1605 | 2000
Budder (6) | 1950 | 1490 | 1144

Actual Control (we want to create a range where nothing happens)

Flap frequency | -a (min) | 0 | +a (max)
Battery (2)
Thot (3) | 1184 | | 1793
Aile (4) | 1744 | | 1139
Elev (5) | 1307 | | 1900
Budder (6) | 1850 | | 1244

6/27

Got the high torque servo working. It accepts a range of 700 to 2294 instead of the theoretical 700-2300 but yeet. Even more theoretical the adafruit docs say it should be 1000-2000 but at this point field robotics does as field robotics does.

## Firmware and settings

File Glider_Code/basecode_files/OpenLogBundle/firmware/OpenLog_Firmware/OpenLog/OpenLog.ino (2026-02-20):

/*
 12-3-09
 Nathan Seidle
 SparkFun Electronics

 OpenLog hardware and firmware are released under the Creative Commons Share Alike v3.0 license.
 http://creativecommons.org/licenses/by-sa/3.0/
 Feel free to use, distribute, and sell varients of OpenLog. All we ask is that you include attribution of 'Based on OpenLog by SparkFun'.

 OpenLog is based on the work of Bill Greiman and sdfatlib: https://github.com/greiman/SdFat-beta

 OpenLog is a simple serial logger based on the ATmega328 running at 16MHz. The whole purpose of this
 logger was to create a logger that just powered up and worked. OpenLog ships with an Arduino/Optiboot
 115200bps serial bootloader running at 16MHz so you can load new firmware with a simple serial
 connection.

 OpenLog has progressed significantly over the past three years. Please see CHANGELOG.md or GitHub commits
 for a full trip down memory lane.

 OpenLog automatically works with 512MB to 64GB micro/SD cards.

 OpenLog runs at 9600bps by default. This is configurable to 1200, 2400, 4800, 9600, 19200, 38400, 57600, and 115200bps. You can alter
 all settings including baud rate and escape characters by editing config.txt found on OpenLog.

 Type '?' to get a list of supported commands.

 During power up, you will see '12<'. '1' indicates the serial connection is established. '2' indicates
 the SD card has been successfully initialized. '<' indicates OpenLog is ready to receive serial characters.

 Recording constant 115200bps datastreams are supported. Throw it everything you've got! To acheive this maximum record rate, please use the
 SD card formatter from : http://www.sdcard.org/consumers/formatter/. The fewer files on the card, the faster OpenLog is able to begin logging.
 200 files is ok. 2GB worth of music and pictures is not.

 To a lower dir, use 'cd ..' instead of 'cd..'.

 Only standard 8.3 file names are supported. "12345678.123" is acceptable. "123456789.123" is not.

 All file names are pushed to upper case. "NewLog.txt" will become "NEWLOG.TXT".

 Type 'set' to enter baud rate configuration menu. Select the baud rate and press enter. You will then
 see a message 'Going to 9600bps...' or some such message. You will need to power down OpenLog, change
 your system UART settings to match the new OpenLog baud rate and then power OpenLog back up.

 If you get OpenLog stuck into an unknown baudrate, there is a safety mechanism built-in. Tie the RX pin
 to ground and power up OpenLog. You should see the LEDs blink back and forth for 2 seconds, then blink
 in unison. Now power down OpenLog and remove the RX/GND jumper. OpenLog is now reset to 9600bps.

 Please note: The preloaded Optiboot serial bootloader is 0.5k, and begins at 0x7E00 (32,256). If the code is
 larger than 32,256 bytes, you will get verification errors during serial bootloading.

 OpenLog regularly shuts down to conserve power. If after 0.5 seconds no characters are received, OpenLog will record 
 any unsaved characters and go to sleep. OpenLog will automatically wake up and continue logging the instant a 
 new character is received.

 1.55mA idle
 15mA actively writing

 Input voltage on VCC can be 3.3 to 12V. Input voltage on RX-I pin must not exceed 6V. Output voltage on
 TX-O pin will not be greater than 3.3V. This may cause problems with some systems - for example if your
 attached microcontroller requires 4V minimum for serial communication (this is rare).

 */

#define __PROG_TYPES_COMPAT__ //Needed to get SerialPort.h to work in Arduino 1.6.x

#include <SPI.h>
#include <SdFat.h> //We do not use the built-in SD.h file because it calls Serial.print
#include <SerialPort.h> //This is a new/beta library written by Bill Greiman. You rock Bill!
#include <EEPROM.h>
#include <FreeStack.h> //Allows us to print the available stack/RAM size

SerialPort<0, 512, 0> NewSerial;
//<port #, RX buffer size, TX buffer size>
//We set the TX buffer to zero because we will be spending most of our 
//time needing to buffer the incoming (RX) characters.

//This is the array within the append file routine
//We have to keep SerialPort buffer sizes reasonable so that when we drop to
//the command shell we have RAM available for the various commands like append
#define LOCAL_BUFF_SIZE 256
//512/256 shell works, 5/5 logs passed
//800/128 shell works, 3/5 logs passed
//672/256 shell works, 2/5 logs passed
//722/256 shell fails
//850/128 shell fails

#include <avr/sleep.h> //Needed for sleep_mode
#include <avr/power.h> //Needed for powering down perihperals such as the ADC/TWI and Timers

#define SD_CHIP_SELECT 10 //On OpenLog this is pin 10

//Debug turns on (1) or off (0) a bunch of verbose debug statements. Normally use (0)
//#define DEBUG  1
#define DEBUG  0

void(* Reset_AVR) (void) = 0; //Way of resetting the ATmega

#define CFG_FILENAME "config.txt" //This is the name of the file that contains the unit settings

#define MAX_CFG "115200,103,214,0,1,1,0\0" //= 115200 bps, escape char of ASCII(103), 214 times, new log mode, verbose on, echo on, ignore RX false. 
#define CFG_LENGTH (strlen(MAX_CFG) + 1) //Length of text found in config file. strlen ignores \0 so we have to add it back 
#define SEQ_FILENAME "SEQLOG00.TXT" //This is the name for the file when you're in sequential mode

//Internal EEPROM locations for the user settings
#define LOCATION_SYSTEM_SETTING		  0x02
#define LOCATION_FILE_NUMBER_LSB	  0x03
#define LOCATION_FILE_NUMBER_MSB	  0x04
#define LOCATION_ESCAPE_CHAR		    0x05
#define LOCATION_MAX_ESCAPE_CHAR	  0x06
#define LOCATION_VERBOSE            0x07
#define LOCATION_ECHO               0x08
#define LOCATION_BAUD_SETTING_HIGH	0x09
#define LOCATION_BAUD_SETTING_MID	  0x0A
#define LOCATION_BAUD_SETTING_LOW	  0x0B
#define LOCATION_IGNORE_RX		      0x0C

#define BAUD_MIN  300
#define BAUD_MAX  1000000

#define MODE_NEWLOG	    0
#define MODE_SEQLOG     1
#define MODE_COMMAND    2

const byte stat1 = 5;  //This is the normal status LED
const byte stat2 = 13; //This is the SPI LED, indicating SD traffic

//Blinking LED error codes
#define ERROR_SD_INIT	    3
#define ERROR_NEW_BAUD	  5
#define ERROR_CARD_INIT   6
#define ERROR_VOLUME_INIT 7
#define ERROR_ROOT_INIT   8
#define ERROR_FILE_OPEN   9

#if !DEBUG
// Using OpenLog in an embedded environment only if not in debug mode. The reason for this
// is that we are out of space if the simple embedded is included
#define INCLUDE_SIMPLE_EMBEDDED
#endif

#ifdef INCLUDE_SIMPLE_EMBEDDED
#define EMBEDDED_END_MARKER  0x08
#endif

//These are bit locations used when testing for simple embedded commands.
#define ECHO			      0x01
#define EXTENDED_INFO		0x02
#define OFF  0x00
#define ON   0x01

SdFat sd;

long setting_uart_speed; //This is the baud rate that the system runs at, default is 9600. Can be 1,200 to 1,000,000
byte setting_systemMode; //This is the mode the system runs in, default is MODE_NEWLOG
byte setting_escape_character; //This is the ASCII character we look for to break logging, default is ctrl+z
byte setting_max_escape_character; //Number of escape chars before break logging, default is 3
byte setting_verbose; //This controls the whether we get extended or simple responses.
byte setting_echo; //This turns on/off echoing at the command prompt
byte setting_ignore_RX; //This flag, when set to 1 will make OpenLog ignore the state of the RX pin when powering up

//The number of command line arguments
//Increase to support more arguments but be aware of the memory restrictions
//command <arg1> <arg2> <arg3> <arg4> <arg5>
#define MAX_COUNT_COMMAND_LINE_ARGS 5

//Used for wild card delete and search
struct commandArg
{
  char* arg; //Points to first character in command line argument
  byte arg_length; //Length of command line argument
};
static struct commandArg cmd_arg[MAX_COUNT_COMMAND_LINE_ARGS];

byte feedbackMode = (ECHO | EXTENDED_INFO);

//Handle errors by printing the error type and blinking LEDs in certain way
//The function will never exit - it loops forever inside blinkError
void systemError(byte errorType)
{
  NewSerial.print(F("Error "));
  switch (errorType)
  {
    case ERROR_CARD_INIT:
      NewSerial.print(F("card.init"));
      blinkError(ERROR_SD_INIT);
      break;
    case ERROR_VOLUME_INIT:
      NewSerial.print(F("volume.init"));
      blinkError(ERROR_SD_INIT);
      break;
    case ERROR_ROOT_INIT:
      NewSerial.print(F("root.init"));
      blinkError(ERROR_SD_INIT);
      break;
    case ERROR_FILE_OPEN:
      NewSerial.print(F("file.open"));
      blinkError(ERROR_SD_INIT);
      break;
  }
}

void setup(void)
{
  pinMode(stat1, OUTPUT);

  //Power down various bits of hardware to lower power usage
  set_sleep_mode(SLEEP_MODE_IDLE);
  sleep_enable();

  //Shut off TWI, Timer2, Timer1, ADC
  ADCSRA &= ~(1 << ADEN); //Disable ADC
  ACSR = (1 << ACD); //Disable the analog comparator
  DIDR0 = 0x3F; //Disable digital input buffers on all ADC0-ADC5 pins
  DIDR1 = (1 << AIN1D) | (1 << AIN0D); //Disable digital input buffer on AIN1/0

  power_twi_disable();
  power_timer1_disable();
  power_timer2_disable();
  power_adc_disable();

  readSystemSettings(); //Load all system settings from EEPROM

  //Setup UART
  NewSerial.begin(setting_uart_speed);
  if (setting_uart_speed < 500)      // check for slow baud rates
  {
    //There is an error in the Serial library for lower than 500bps.
    //This fixes it. See issue 163: https://github.com/sparkfun/OpenLog/issues/163
    // redo USART baud rate configuration
    UBRR0 = (F_CPU / (16UL * setting_uart_speed)) - 1;
    UCSR0A &= ~_BV(U2X0);
  }
  NewSerial.print(F("1"));

  //Setup SD & FAT
  if (!sd.begin(SD_CHIP_SELECT, SPI_FULL_SPEED)) systemError(ERROR_CARD_INIT);
  if (!sd.chdir()) systemError(ERROR_ROOT_INIT); //Change to root directory. All new file creation will be in root.

  NewSerial.print(F("2"));

  //Search for a config file and load any settings found. This will over-ride previous EEPROM settings if found.
  readConfigFile();

  if (setting_ignore_RX == OFF) //If we are NOT ignoring RX, then
    checkEmergencyReset(); //Look to see if the RX pin is being pulled low

#if DEBUG
  NewSerial.print(F("FreeStack: "));
  NewSerial.println(FreeStack());
#endif

}

void loop(void)
{
  //If we are in new log mode, find a new file name to write to
  if (setting_systemMode == MODE_NEWLOG)
    appendFile(newLog()); //Append the file name that newLog() returns

  //If we are in sequential log mode, determine if seqLog.txt has been created or not, and then open it for logging
  if (setting_systemMode == MODE_SEQLOG)
    seqLog();

  //Once either one of these modes exits, go to normal command mode, which is called by returning to main()
  commandShell();
}

//Log to a new file everytime the system boots
//Checks the spots in EEPROM for the next available LOG# file name
//Updates EEPROM and then appends to the new log file.
//Limited to 65535 files but this should not always be the case.
char* newLog(void)
{
  byte msb, lsb;
  unsigned int newFileNumber;

  SdFile newFile; //This will contain the file for SD writing

  //Combine two 8-bit EEPROM spots into one 16-bit number
  lsb = EEPROM.read(LOCATION_FILE_NUMBER_LSB);
  msb = EEPROM.read(LOCATION_FILE_NUMBER_MSB);

  newFileNumber = msb;
  newFileNumber = newFileNumber << 8;
  newFileNumber |= lsb;

  //If both EEPROM spots are 255 (0xFF), that means they are un-initialized (first time OpenLog has been turned on)
  //Let's init them both to 0
  if ((lsb == 255) && (msb == 255))
  {
    newFileNumber = 0; //By default, unit will start at file number zero
    EEPROM.write(LOCATION_FILE_NUMBER_LSB, 0x00);
    EEPROM.write(LOCATION_FILE_NUMBER_MSB, 0x00);
  }

  //The above code looks like it will forever loop if we ever create 65535 logs
  //Let's quit if we ever get to 65534
  //65534 logs is quite possible if you have a system with lots of power on/off cycles
  if (newFileNumber == 65534)
  {
    //Gracefully drop out to command prompt with some error
    NewSerial.print(F("!Too many logs:1!"));
    return (0); //Bail!
  }

  //If we made it this far, everything looks good - let's start testing to see if our file number is the next available
#if DEBUG
  NewSerial.print(F("Found file number: "));
  NewSerial.println(newFileNumber);
#endif

  //There is a weird EEPROM power-up glitch that causes the newFileNumber to advance
  //arbitrarily. This fixes that problem.
  if(newFileNumber > 0) newFileNumber--;

  //Search for next available log spot
  static char newFileName[13]; //Bug fix from ystark's pull request: https://github.com/sparkfun/OpenLog/pull/189
  while (1)
  {
    sprintf_P(newFileName, PSTR("LOG%05u.TXT"), newFileNumber); //Splice the new file number into this file name

    // O_CREAT - create the file if it does not exist
    // O_APPEND - seek to the end of the file prior to each write
    // O_WRITE - open for write
    // O_EXCL - if O_CREAT and O_EXCEL are set, open() shall fail if file exists 

    //Try to open file, if it opens (file doesn't exist), then break
    if (newFile.open(newFileName, O_CREAT | O_EXCL | O_WRITE)) break;

    //Try to open file and see if it is empty. If so, use it.
    if (newFile.open(newFileName, O_READ))
    {
      if (newFile.fileSize() == 0)
      {
        newFile.close();        // Close this existing file we just opened.
        return (newFileName); // Use existing empty file.
      }
      newFile.close(); // Close this existing file we just opened.
    }

    //Try the next number
    newFileNumber++;
    if (newFileNumber > 65533) //There is a max of 65534 logs
    {
      NewSerial.print(F("!Too many logs:2!"));
      return (0); //Bail!
    }
  }
  newFile.close(); //Close this new file we just opened

  newFileNumber++; //Increment so the next power up uses the next file #

  //Record new_file number to EEPROM
  lsb = (byte)(newFileNumber & 0x00FF);
  msb = (byte)((newFileNumber & 0xFF00) >> 8);

  EEPROM.write(LOCATION_FILE_NUMBER_LSB, lsb); // LSB

  if (EEPROM.read(LOCATION_FILE_NUMBER_MSB) != msb)
    EEPROM.write(LOCATION_FILE_NUMBER_MSB, msb); // MSB

#if DEBUG
  NewSerial.print(F("Stored file number: "));
  NewSerial.println(newFileNumber);

  NewSerial.print(F("Created new file: "));
  NewSerial.println(newFileName);
#endif

  return (newFileName);
}

//Log to the same file every time the system boots, sequentially
//Checks to see if the file SEQLOG.txt is available
//If not, create it
//If yes, append to it
//Return 0 on error
//Return anything else on success
void seqLog(void)
{
  SdFile seqFile;

  char sequentialFileName[strlen(SEQ_FILENAME)]; //Limited to 8.3
  strcpy_P(sequentialFileName, PSTR(SEQ_FILENAME)); //This is the name of the config file. 'config.sys' is probably a bad idea.

  //Try to create sequential file
  if (!seqFile.open(sequentialFileName, O_CREAT | O_WRITE))
  {
    NewSerial.println(F("Error creating SEQLOG"));
    return;
  }

  seqFile.close(); //Close this new file we just opened

  appendFile(sequentialFileName);
}

//This is the most important function of the device. These loops have been tweaked as much as possible.
//Modifying this loop may negatively affect how well the device can record at high baud rates.
//Appends a stream of serial data to a given file
//Does not exit until escape character is received the correct number of times
//Returns 0 on error
//Returns 1 on success
byte appendFile(char* fileName)
{
  SdFile workingFile;

  // O_CREAT - create the file if it does not exist
  // O_APPEND - seek to the end of the file prior to each write
  // O_WRITE - open for write
  if (!workingFile.open(fileName, O_CREAT | O_APPEND | O_WRITE)) systemError(ERROR_FILE_OPEN);

  if (workingFile.fileSize() == 0) {
    //This is a trick to make sure first cluster is allocated - found in Bill's example/beta code
    workingFile.rewind();
    workingFile.sync();
  }

  //This is the 2nd buffer. It pulls from the larger Serial buffer as quickly as possible.
  //The built-in Arduino serial buffer is 64 bytes: https://www.arduino.cc/en/Serial/Available
  byte localBuffer[LOCAL_BUFF_SIZE];

  byte checkedSpot;
  byte escapeCharsReceived = 0;

  const unsigned int MAX_IDLE_TIME_MSEC = 500; //The number of milliseconds before unit goes to sleep
  unsigned long lastSyncTime = millis(); //Keeps track of the last time the file was synced

#if DEBUG
  NewSerial.print(F("FreeStack: "));
  NewSerial.println(FreeStack());
#endif

  NewSerial.print(F("<")); //give a different prompt to indicate no echoing
  digitalWrite(stat1, HIGH); //Turn on indicator LED

  //Check if we should ignore escape characters
  //If we are ignoring escape characters the recording loop is infinite and can be made shorter (less checking)
  //This should allow for recording at higher incoming rates
  if (setting_max_escape_character == 0)
  {
    //Start recording incoming characters
    //With no escape characters, do this infinitely
    while (1)
    {
      byte charsToRecord = NewSerial.read(localBuffer, sizeof(localBuffer)); //Read characters from global buffer into the local buffer
      if (charsToRecord > 0) //If we have characters, check for escape characters
      {
        workingFile.write(localBuffer, charsToRecord); //Record the buffer to the card

        toggleLED(stat1); //Toggle the STAT1 LED each time we record the buffer
      }
      //No characters received?
      else if ( (millis() - lastSyncTime) > MAX_IDLE_TIME_MSEC) //If we haven't received any characters in 2s, goto sleep
      {
        workingFile.sync(); //Sync the card before we go to sleep

        digitalWrite(stat1, LOW); //Turn off stat LED to save power

        power_timer0_disable(); //Shut down peripherals we don't need
        power_spi_disable();
        sleep_mode(); //Stop everything and go to sleep. Wake up if serial character received

        power_spi_enable(); //After wake up, power up peripherals
        power_timer0_enable();

        escapeCharsReceived = 0; // Clear the esc flag as it has timed out
        lastSyncTime = millis(); //Reset the last sync time to now
      }
    }
  }

  //We only get this far if escape characters are more than zero

  //Start recording incoming characters
  while (escapeCharsReceived < setting_max_escape_character)
  {
    byte charsToRecord = NewSerial.read(localBuffer, sizeof(localBuffer)); //Read characters from global buffer into the local buffer
    if (charsToRecord > 0) //If we have characters, check for escape characters
    {
      if (localBuffer[0] == setting_escape_character)
      {
        escapeCharsReceived++;

        //Scan the local buffer for esacape characters
        for (checkedSpot = 1 ; checkedSpot < charsToRecord ; checkedSpot++)
        {
          if (localBuffer[checkedSpot] == setting_escape_character) {
            escapeCharsReceived++;
            //If charsToRecord is greater than 3 there's a chance here where we receive three esc chars
            // and then reset the variable: 26 26 26 A T + would not escape correctly
            if (escapeCharsReceived == setting_max_escape_character) break;
          }
          else
            escapeCharsReceived = 0;
        }
      }
      else
        escapeCharsReceived = 0;

      workingFile.write(localBuffer, charsToRecord); //Record the buffer to the card

      toggleLED(stat1); //Toggle the STAT1 LED each time we record the buffer
    }
    //No characters recevied?
    else if ( (millis() - lastSyncTime) > MAX_IDLE_TIME_MSEC) //If we haven't received any characters in 2s, goto sleep
    {
      workingFile.sync(); //Sync the card before we go to sleep

      digitalWrite(stat1, LOW); //Turn off stat LED to save power

      power_timer0_disable(); //Shut down peripherals we don't need
      power_spi_disable();
      sleep_mode(); //Stop everything and go to sleep. Wake up if serial character received

      power_spi_enable(); //After wake up, power up peripherals
      power_timer0_enable();

      escapeCharsReceived = 0; // Clear the esc flag as it has timed out
      lastSyncTime = millis(); //Reset the last sync time to now
    }

  }

  workingFile.sync();

  //Remove the escape characters from the end of the file
  if(setting_max_escape_character > 0) 
    workingFile.truncate(workingFile.fileSize() - setting_max_escape_character);
  
  workingFile.close(); // Done recording, close out the file

  digitalWrite(stat1, LOW); // Turn off indicator LED

  NewSerial.print(F("~")); // Indicate a successful record

  return (1); //Success!
}

//The following are system functions needed for basic operation
//=-=-=-=-=-=-=-=-=-=-=-=-=-=-=-=-=-=-=-=-=-=-=-=-=-=-=

//Blinks the status LEDs to indicate a type of error
void blinkError(byte ERROR_TYPE) {
  while (1) {
    for (int x = 0 ; x < ERROR_TYPE ; x++) {
      digitalWrite(stat1, HIGH);
      delay(200);
      digitalWrite(stat1, LOW);
      delay(200);
    }

    delay(2000);
  }
}
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

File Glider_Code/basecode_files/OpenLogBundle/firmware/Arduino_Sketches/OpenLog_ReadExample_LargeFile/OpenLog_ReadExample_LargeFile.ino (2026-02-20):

/*
 Example of reading of a large file
 By: Nathan Seidle
 SparkFun Electronics
 Date: September 22nd, 2013
 License: This code is public domain but you buy me a beer if you use this and we meet someday (Beerware license).

 This example connects to OpenLog over the hardware serial pins (pins 0 and 1) at 9600bps,
 then opens a file called 'bigtext.txt',
 then reports the contents of that file to a Bluetooth (or other serial) device over software serial on pins 9/10 at 14400bps.
 
 Note: We listen to OpenLog at 9600 but report to Bluetooth at 14400 in order to avoid dropping characters. 115200bps,
 57600bps, 19200 and 14400 works great. Reporting to the device hooked to softare serial at 9600 will not work.
 
 Note: You must disconnect OpenLog from the Arduino's TX and RX pins when flashing new firmware onto the Arduino.
 
 Connect the following OpenLog pins to Arduino:
 TXO of OpenLog to pin 0 on the Arduino
 RXI to 1
 GRN to 4
 VCC to 5V
 GND to GND
 
 Connect the following Bluetooth pins to Arduino:
 RXI of Bluetooth serial device to pin 9 on the Arduino
 TXO to 10 (not really used)
 
 This example code assumes the OpenLog is set to operate at 9600bps in NewLog mode, meaning OpenLog 
 should power up and output '12<'. This code then sends the three escape characters and then sends 
 the commands to create a new random file called log###.txt where ### is a random number from 0 to 999.
 The example code will then read back the random file and print it to the serial terminal.
 
 This code assume OpenLog is in the default state of 9600bps with ASCII-26 as the esacape character.
 If you're unsure, make sure the config.txt file contains the following: 9600,26,3,0
 
 Be careful when sending commands to OpenLog. println() sends extra newline characters that 
 cause problems with the command parser. The new v2.51 ignores \n commands so it should be easier to 
 talk to on the command prompt level. This example code works with all OpenLog v2 and higher.
 */

#include <SoftwareSerial.h>

//-=-=-=-=-=-=-=-=-=-=-=-=-=-=-=-=-=-=-=-=-=-=-=-=-=-=-=-=-=-=-=-=-=-
//Connect Bluetooth module via software serial
SoftwareSerial BluetoothOut(10, 9); //Soft Bluetooth RX on 10, soft bluetooth TX on 9

int resetOpenLog = 4; //This pin resets OpenLog. Connect pin 4 to pin GRN on OpenLog.
//-=-=-=-=-=-=-=-=-=-=-=-=-=-=-=-=-=-=-=-=-=-=-=-=-=-=-=-=-=-=-=-=-=-

int statLED = 13;

void setup() {                
  pinMode(statLED, OUTPUT);
  Serial.begin(9600);
  
  setupOpenLog(); //Resets logger and waits for the '<' I'm alive character

  BluetoothOut.begin(14400); //Start connection with Bluetooth
  BluetoothOut.println("Bluetooth connection online");
}

void loop() {

  //Now let's read back
  gotoCommandMode(); //Puts OpenLog in command mode
  readFile("bigtext.txt"); //Count the number of characters in this file
  //readFile("smltext.txt"); //Small text is only a few dozen characters - used to locate white space chars

  BluetoothOut.println();
  BluetoothOut.println("File read complete");

  //Infinite loop
  while(1) {
    digitalWrite(13, HIGH);
    delay(250);
    digitalWrite(13, LOW);
    delay(250);
  }
}

//Reads the contents of a given file and dumps it to the serial terminal
//This function assumes the OpenLog is in command mode
void readFile(char *fileName) {

  //BluetoothOut.println("Counting characters, be right back");

  //Old way
  Serial.print("read ");
  Serial.print(fileName);
  Serial.write(13); //This is \r

  //New way
  //OpenLog.print("read ");
  //OpenLog.println(filename); //regular println works with OpenLog v2.51 and above

  //The OpenLog echos the commands we send it by default so we have 'read log823.txt\r' sitting 
  //in the RX buffer. Let's try to not print this.
  while(1) {
    if(Serial.available())
      if(Serial.read() == '\r') break;
  }  

  //This will listen for characters coming from OpenLog and print them to the terminal
  //This relies heavily on the SoftSerial buffer not overrunning. This will probably not work
  //above 38400bps.
  //This loop will stop listening after 1 second of no characters received

  int charactersRead = 0;

  for(int timeOut = 0 ; timeOut < 1000 ; timeOut++)
  {
    while(Serial.available())
    {
      BluetoothOut.print(Serial.read()); //Take the character from OpenLog and push it to software serial TX
      
      charactersRead++;//= charsToRead;
      
      timeOut = 0;
    }

    delay(1);
    
  }
  
  //BluetoothOut.print("Characters read: ");
  //BluetoothOut.println(charactersRead);

  //This is not perfect. The above loop will print the '.'s from the log file. These are the two escape characters
  //recorded before the third escape character is seen.
  //It will also print the '>' character. This is the OpenLog telling us it is done reading the file.  

  //This function leaves OpenLog in command mode
}

//This function pushes OpenLog into command mode
void gotoCommandMode(void) {
  //Send three control z to enter OpenLog command mode
  //Works with Arduino v1.0
  Serial.write(26);
  Serial.write(26);
  Serial.write(26);

  //Wait for OpenLog to respond with '>' to indicate we are in command mode
  while(1) {
    if(Serial.available())
      if(Serial.read() == '>') break;
  }
}

//Setups up the software serial, resets OpenLog so we know what state it's in, and waits
//for OpenLog to come online and report '<' that it is ready to receive characters to record
void setupOpenLog(void) {
  pinMode(resetOpenLog, OUTPUT);

  //Reset OpenLog
  digitalWrite(resetOpenLog, LOW);
  delay(500);
  digitalWrite(resetOpenLog, HIGH);

  //Wait for OpenLog to respond with '<' to indicate it is alive and recording to a file
  while(1) {
    if(Serial.available())
      if(Serial.read() == '<') break;
  }
}

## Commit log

2026-02-20 added all project files
    [Ahtesham_servo mount.stl, Basic Servo Mount Model.stl, Cover_v1 v2.f3d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]
2026-02-20 Add README for Flapping Winged Glider project
    Added detailed project overview, research goals, firmware information, mechanical design, and future work for the Flapping Winged Glider project.
